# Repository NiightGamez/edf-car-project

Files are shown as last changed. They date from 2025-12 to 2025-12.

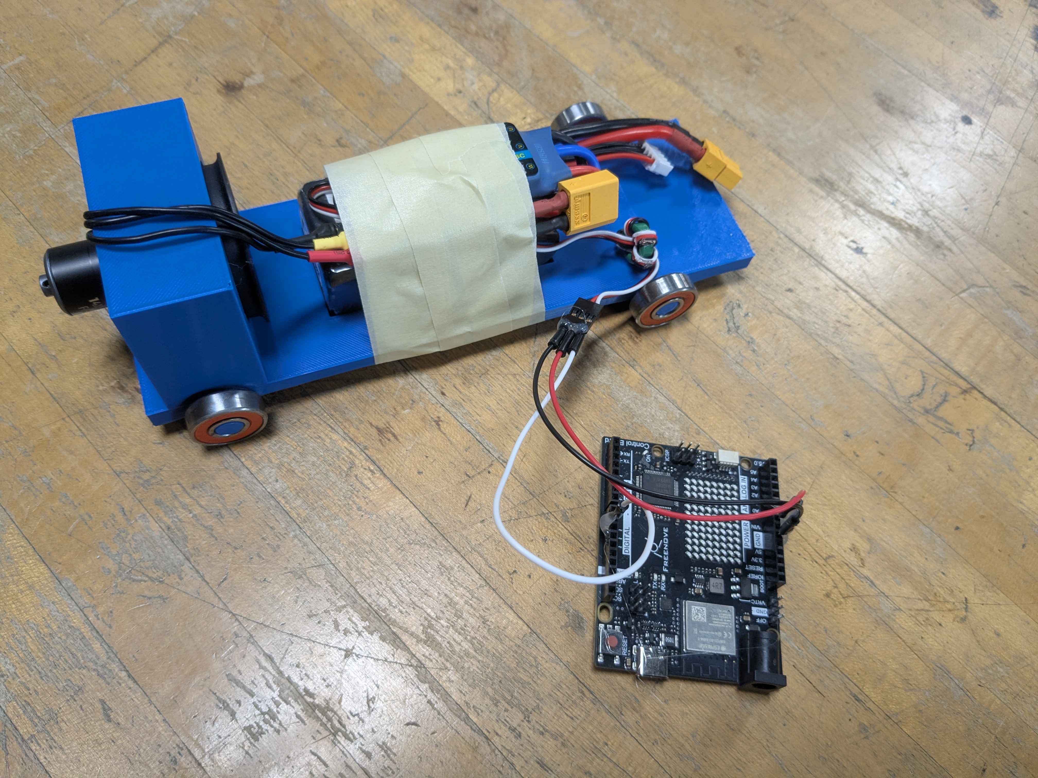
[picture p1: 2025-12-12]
PXL_20251212_173652594.jpg

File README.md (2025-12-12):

# 🚀 Pinewood Derby Ducted Fan Car Control System

This system uses an **Arduino Uno R4 WiFi** board as the master controller for a ducted fan Pinewood Derby car. It features BLE-required arming for safety, dual trigger modes (Ultrasonic Auto-Start or BLE Manual Trigger), and real-time status feedback via the onboard LED Matrix and Serial Monitor.

## 📋 Parts List

| Component | Function | Status |
| :--- | :--- | :--- |
| **Microcontroller**  | Arduino Uno R4 WiFi (or Freenove V5) | **Have** |
| **Trigger Sensor** | HC-SR04 Ultrasonic Sensor | **Have** |
| **Motor Controller** | 30A Brushless Electronic Speed Controller (ESC) | **Have** |
| **Propulsion** | 30mm Ducted Fan Unit (Brushless Motor) | **Have** |
| **Power** | 3S 11.1V 1500mAh LiPo Battery | **Have** |
## 💡 System Logic

1.  **Safety Master Key:** The system is completely inert (**DISARMED**) until a phone connects via BLE.
2.  **Arming:** Connecting via BLE sends the `THROTTLE_MIN` pulse to the ESC, arming the motor controller and enabling the trigger system.
3.  **Mode Select:** The BLE connection allows the user to switch between **MANUAL TRIGGER** and **SENSOR AUTO-TRIGGER** mode.
4.  **Race:** When triggered, the system simulates a full throttle run for 3 seconds.
## Arming:
- **BLE IS REQUIRED**
	- Connect with nRF Connnect
	```
	UUID Ending with 002
		- Set to 01 for Manual Trigger Mode (Disables sensor. Car is fired only by BLE Command)
		- Set to 02 Enables sensor. (Car fires automatically when pin drops)
	UUID Ending with 001
		- Set to 01 for Start Race/Fire Engine (Manual Sensor Overide) 	  
	```
	
## 🛠️ Initial Setup Instructions

1.  **Install Libraries:** In the Arduino IDE, install the following libraries:
    * `Servo` (Standard library)
    * `Arduino_LED_Matrix` (For the onboard matrix)
    * `ArduinoBLE` (For Bluetooth Low Energy control)

2.  **Upload Code:** Copy the contents of edf_car.ino` and upload it to your Arduino board.

3.  **BLE Connection (Master Key):**
    * Download **nRF Connect** on your Android phone.
    * Connect the battery to the ESC.
    * Scan for the device **`DerbyCarV5`** and connect. The system will switch from **DISARMED** (Matrix clear) to **MANUAL READY** (Matrix full border).

4.  **Mode Switching via BLE:**
    * Find the **Mode Characteristic** (UUID ending in `...0002`).
    * **Manual Trigger Mode:** Write Hex value **`01`**. (Default mode).
    * **Sensor Auto-Trigger Mode:** Write Hex value **`02`**.

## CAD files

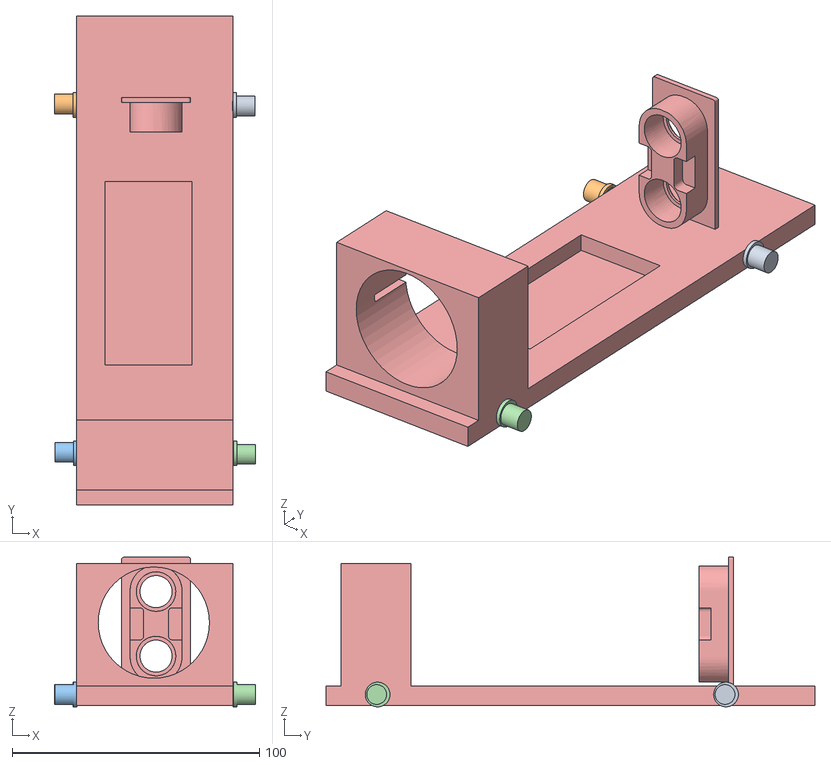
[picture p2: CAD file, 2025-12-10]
cad-files/tinker.obj
81.3 x 197.9 x 60.6
obj_0
obj_1
obj_2
obj_3
obj_4

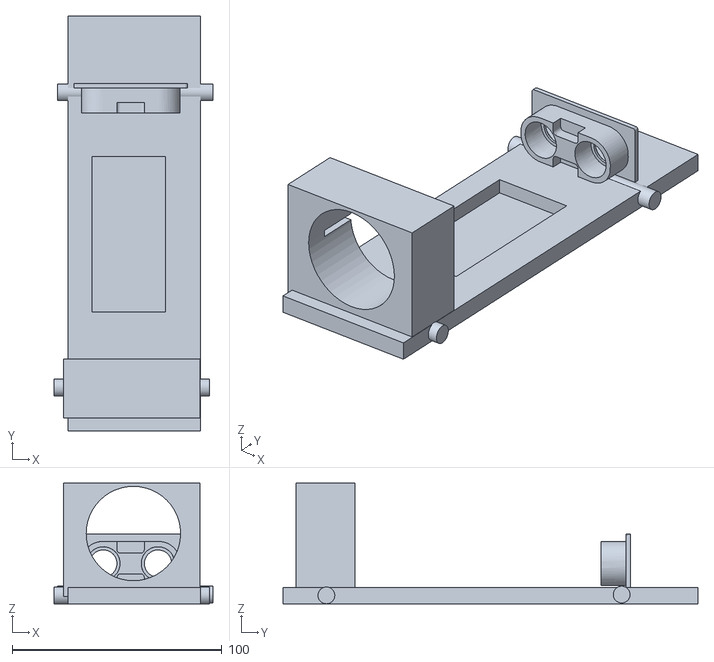
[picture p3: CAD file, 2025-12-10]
cad-files/Car3v3.stl
75.7 x 197.9 x 57.5

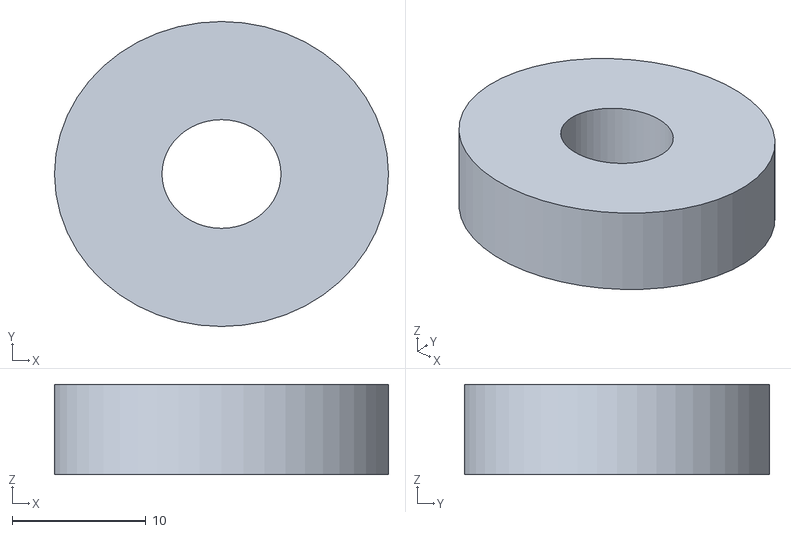
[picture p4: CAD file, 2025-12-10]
cad-files/wheeltest.stl
25.0 x 22.8 x 6.75

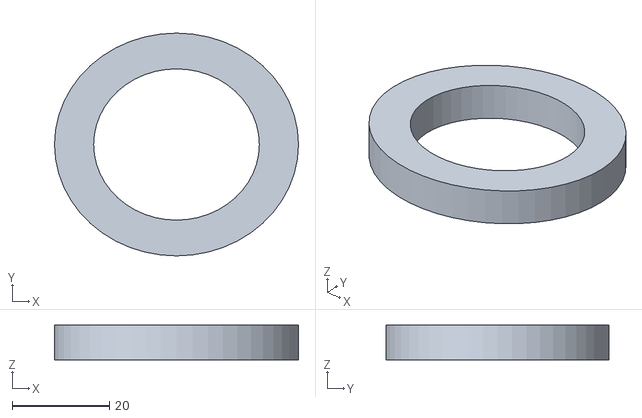
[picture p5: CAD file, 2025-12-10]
cad-files/wheeltest2.stl
50.1 x 45.8 x 7.15

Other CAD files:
cad-files/CarV4.stl

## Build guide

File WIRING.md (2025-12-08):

# ⚡ Wiring and Power Flow Diagram

**⚠️ WARNING:** The LiPo battery supplies 11.1V. Use caution. Ensure the **Fan Motor is disconnected** from the ESC during initial setup and testing. The ESC's BEC provides safe 5V power to the Arduino.

## 🔌 Signal and Control Connections

| Component | Pin (Wire Color) | Arduino Uno R4 Pin | Notes |
| :--- | :--- | :--- | :--- |
| **ESC Signal** | Signal (White) | **D9** | PWM output for throttle control. |
| **Ultrasonic Trigger**  | Trig (Red) | **D5** | Sends the sonic pulse. |
| **Ultrasonic Echo** | Echo (Orange) | **D6** | Receives the reflected pulse. |
| **Ultrasonic VCC (5V)** | VCC (Brown) | **Power 5v** | Sends 5V power to sensor |
| **Ultrasonic GND** | GND (Yellow) | **Power GND** | Supplies ground for sensor |

## 🔋 Power Connections

| Component | Pin (Wire Color) | Arduino Uno R4 Pin | Voltage |
| :--- | :--- | :--- | :--- |
| **LiPo Battery** (11.1V) | Large Red/Black | Connects ONLY to **30A ESC Power Input** | High Power |
| **ESC BEC Output** | Red | **5V Pin** | Powers the Arduino. |
| **ESC BEC Output** | Black/Brown | **GND Pin** | Common Ground. |

## Power Flow Summary

1.  **LiPo** $\rightarrow$ **ESC Power Input** (11.1V)
2.  **ESC** $\rightarrow$ **Ducted Fan Motor** (Controls motor speed)
3.  **ESC BEC** $\rightarrow$ **Arduino 5V/GND** (5V regulated power)
4.  **Arduino** $\rightarrow$ **HC-SR04** (Powered by 5V rail)

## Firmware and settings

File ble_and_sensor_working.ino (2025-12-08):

#include <Servo.h>

#include "Arduino_LED_Matrix.h"

#include <ArduinoBLE.h>

  

// Initialize Objects

Servo fanESC;

ArduinoLEDMatrix matrix;

  

// --- Pin Definitions ---

const int ESC_PIN = 9;

const int TRIG_PIN = 5;

const int ECHO_PIN = 6;

  

// --- Sensor & Control Constants ---

const float SPEED_OF_SOUND = 0.0343;

const int LAUNCH_THRESHOLD_CM = 3.1; // Fan ON if distance > 10 cm or Out of Range

const int SHUTDOWN_THRESHOLD_CM = 3; // Fan OFF if distance <= 9 cm

  

// --- CRITICAL THROTTLE CONSTANTS ---

const int THROTTLE_MIN = 1000; // 0% throttle (Arming and Stopping)

const int THROTTLE_MAX = 2000; // 100% throttle

  

// --- State Variables (Defined globally) ---

bool isArmed = false;

bool sensor_enabled = false;

bool isFanRunning = false;

int blink_state = 0;

  

// Track the current mode for change detection

enum Mode { MODE_DISARMED, MODE_MANUAL_READY, MODE_FAN_ON, MODE_SENSOR_READY };

Mode current_mode = MODE_DISARMED;

  

// --- BLE Definitions (Defined globally) ---

BLEService carService("19B10000-E8F2-537E-4F6C-D104768A1214");

BLEIntCharacteristic startCommandCharacteristic("19B10001-E8F2-537E-4F6C-D104768A1214", BLERead | BLEWrite);

BLEIntCharacteristic modeCharacteristic("19B10002-E8F2-537E-4F6C-D104768A1214", BLERead | BLEWrite);

  

// --- LED Matrix Patterns (Defined globally) ---

uint8_t BLE_CONNECTED_PATTERN[8][12] = {

{ 1, 1, 1, 1, 1, 1, 1, 1, 1, 1, 1, 1 }, { 1, 0, 0, 0, 0, 0, 0, 0, 0, 0, 0, 1 },

{ 1, 0, 0, 0, 0, 0, 0, 0, 0, 0, 0, 1 }, { 1, 0, 0, 0, 0, 0, 0, 0, 0, 0, 0, 1 },

{ 1, 0, 0, 0, 0, 0, 0, 0, 0, 0, 0, 1 }, { 1, 0, 0, 0, 0, 0, 0, 0, 0, 0, 0, 1 },

{ 1, 0, 0, 0, 0, 0, 0, 0, 0, 0, 0, 1 }, { 1, 1, 1, 1, 1, 1, 1, 1, 1, 1, 1, 1 }

};

uint8_t FAN_ON_PATTERN[8][12] = {

{ 1, 1, 1, 1, 1, 1, 1, 1, 1, 1, 1, 1 }, { 1, 1, 1, 1, 1, 1, 1, 1, 1, 1, 1, 1 },

{ 1, 1, 1, 1, 1, 1, 1, 1, 1, 1, 1, 1 }, { 1, 1, 1, 1, 1, 1, 1, 1, 1, 1, 1, 1 },

{ 1, 1, 1, 1, 1, 1, 1, 1, 1, 1, 1, 1 }, { 1, 1, 1, 1, 1, 1, 1, 1, 1, 1, 1, 1 },

{ 1, 1, 1, 1, 1, 1, 1, 1, 1, 1, 1, 1 }, { 1, 1, 1, 1, 1, 1, 1, 1, 1, 1, 1, 1 }

};

uint8_t SWITCH_PATTERN[8][12] = {

{ 1, 1, 1, 1, 1, 1, 1, 1, 1, 1, 1, 1 }, { 0, 0, 0, 0, 0, 0, 0, 0, 0, 0, 0, 0 },

{ 1, 1, 1, 1, 1, 1, 1, 1, 1, 1, 1, 1 }, { 0, 0, 0, 0, 0, 0, 0, 0, 0, 0, 0, 0 },

{ 1, 1, 1, 1, 1, 1, 1, 1, 1, 1, 1, 1 }, { 0, 0, 0, 0, 0, 0, 0, 0, 0, 0, 0, 0 },

{ 1, 1, 1, 1, 1, 1, 1, 1, 1, 1, 1, 1 }, { 0, 0, 0, 0, 0, 0, 0, 0, 0, 0, 0, 0 }

};

uint8_t DISARMED_DOT[8][12] = {

{ 0, 0, 0, 0, 0, 0, 0, 0, 0, 0, 0, 0 }, { 0, 0, 0, 0, 0, 0, 0, 0, 0, 0, 0, 0 },

{ 0, 0, 0, 0, 0, 0, 0, 0, 0, 0, 0, 0 }, { 0, 0, 0, 0, 0, 1, 1, 0, 0, 0, 0, 0 },

{ 0, 0, 0, 0, 0, 1, 1, 0, 0, 0, 0, 0 }, { 0, 0, 0, 0, 0, 0, 0, 0, 0, 0, 0, 0 },

{ 0, 0, 0, 0, 0, 0, 0, 0, 0, 0, 0, 0 }, { 0, 0, 0, 0, 0, 0, 0, 0, 0, 0, 0, 0 }

};

  
  

// ====================================

// CORE FUNCTIONS

// ====================================

  

float getDistance_cm() {

digitalWrite(TRIG_PIN, LOW); delayMicroseconds(2);

digitalWrite(TRIG_PIN, HIGH); delayMicroseconds(10);

digitalWrite(TRIG_PIN, LOW);

long duration = pulseIn(ECHO_PIN, HIGH, 30000);

if (duration == 0) return 400.0;

return (duration * SPEED_OF_SOUND) / 2.0;

}

  

void setFanPower(bool state) {

if (state == true) {

if (!isFanRunning) {

fanESC.writeMicroseconds(THROTTLE_MAX);

isFanRunning = true;

Serial.println("COMMAND: FAN ACTIVATED (2000us)");

}

} else {

if (isFanRunning) {

fanESC.writeMicroseconds(THROTTLE_MIN);

isFanRunning = false;

Serial.println("COMMAND: FAN SHUTDOWN (1000us)");

}

}

}

  

// ====================================

// DEBUG & DISPLAY FUNCTION

// ====================================

  

void displayStatus(float dist_cm, bool ble_connected) {

// 1. DETERMINE NEW MODE

Mode new_mode;

if (!isArmed) { new_mode = MODE_DISARMED; }

else if (isFanRunning) { new_mode = MODE_FAN_ON; }

else if (sensor_enabled) { new_mode = MODE_SENSOR_READY; }

else { new_mode = MODE_MANUAL_READY; }

  

// 2. DETECT SWITCH AND NOTIFY USER

if (new_mode != current_mode) {

current_mode = new_mode;

Serial.print("--------------------------------");

Serial.print("\nMODE SWITCHED TO: ");

if (new_mode == MODE_DISARMED) Serial.println("DISARMED");

else if (new_mode == MODE_FAN_ON) Serial.println("FAN IS RUNNING");

else if (new_mode == MODE_SENSOR_READY) Serial.println("SENSOR ACTIVE / FAN OFF");

else if (new_mode == MODE_MANUAL_READY) Serial.println("MANUAL READY / FAN OFF");

Serial.println("--------------------------------");

matrix.renderBitmap(SWITCH_PATTERN, 8, 12);

delay(50);

}

  

// 3. CONTINUOUS STATUS DISPLAY

blink_state = (blink_state + 1) % 10;

  

Serial.print("Status: ");

Serial.print(current_mode == MODE_DISARMED ? "DISARMED" : (isFanRunning ? "FAN ON" : "ARMED, FAN OFF"));

if (sensor_enabled) {

Serial.print(" | Dist: ");

if (dist_cm >= 400.0) { Serial.println("Out of Range"); }

else { Serial.print(dist_cm); Serial.println(" cm"); }

} else {

Serial.println(" | Sensor: Disabled");

}

  

// LED Matrix: Continuous Mode Indicator

if (current_mode == MODE_FAN_ON) { matrix.renderBitmap(FAN_ON_PATTERN, 8, 12); }

else if (current_mode == MODE_MANUAL_READY || current_mode == MODE_SENSOR_READY) {

matrix.renderBitmap(BLE_CONNECTED_PATTERN, 8, 12);

} else if (current_mode == MODE_DISARMED) {

if (blink_state > 5) { matrix.renderBitmap(DISARMED_DOT, 8, 12); }

else { matrix.clear(); }

}

}

  
  

// ====================================

// SETUP FUNCTION

// ====================================

void setup() {

Serial.begin(9600);

matrix.begin();

matrix.clear();

pinMode(TRIG_PIN, OUTPUT);

pinMode(ECHO_PIN, INPUT);

  

// --- BLE Setup (CRITICAL FIX: Initialize BLE first) ---

if (!BLE.begin()) {

Serial.println("!!! FATAL ERROR: BLE initialization failed! Program Halted. !!!");

while (1);

}

// --- ESC Attach (Attach after BLE succeeds) ---

fanESC.attach(ESC_PIN);

// Attach BLE characteristics to service

BLE.setAdvertisedService(carService);

carService.addCharacteristic(startCommandCharacteristic);

BLE.addService(carService);

carService.addCharacteristic(modeCharacteristic);

BLE.addService(carService);

BLE.setLocalName("DerbyCarV5");

Serial.println("System Initialized. Awaiting BLE Connection to Arm ESC.");

current_mode = MODE_DISARMED;

BLE.advertise();

}

  

// ====================================

// LOOP FUNCTION (DIRECT SENSOR CONTROL)

// ====================================

void loop() {

BLEDevice central = BLE.central();

bool ble_connected = central;

float distance = 0.0;

  

// --- A. BLE-REQUIRED ARMING/DISARMING ---

if (ble_connected && !isArmed) {

Serial.println("\n--- BLE CONNECTED: ARMING ESC NOW (ESC Must Beep) ---");

fanESC.writeMicroseconds(THROTTLE_MIN);

isArmed = true;

delay(100);

}

if (!ble_connected && isArmed) {

Serial.println("\n--- BLE DISCONNECTED: DISARMING CAR ---");

setFanPower(false); // Shut down fan

isArmed = false;

current_mode = MODE_DISARMED;

}

// --- B. BLE COMMAND HANDLING ---

if (isArmed) {

// 1. CHECK FOR MODE CHANGE COMMAND (Fixes Mode Switch Issue)

if (modeCharacteristic.written()) {

int mode_cmd = modeCharacteristic.value();

if (mode_cmd == 2) {

sensor_enabled = true;

Serial.println("Mode set to SENSOR AUTO-TRIGGER.");

} else {

sensor_enabled = false;

Serial.println("Mode set to MANUAL TRIGGER.");

}

modeCharacteristic.writeValue(mode_cmd); // Acknowledge write

}

// 2. CHECK FOR FAN ON/OFF COMMAND (Manual override for testing)

if (startCommandCharacteristic.written()) {

int command = startCommandCharacteristic.value();

if (command == 1) { setFanPower(true); } else if (command == 0) { setFanPower(false); }

startCommandCharacteristic.writeValue(command);

}

}

  

// --- C. DIRECT SENSOR CONTROL LOGIC (MODIFIED FOR OUT OF RANGE) ---

if (isArmed && sensor_enabled) {

distance = getDistance_cm();

// 1. SAFETY SHUTDOWN CHECK: Turn fan OFF if distance is <= 9 cm

if (distance <= SHUTDOWN_THRESHOLD_CM) {

if (isFanRunning) {

Serial.println("SENSOR SHUTDOWN: Obstacle <= 9cm. FAN OFF.");

}

setFanPower(false);

}

// 2. LAUNCH/KEEP RUNNING CHECK: Turn fan ON if distance > 10 cm OR out of range (400cm)

else if (distance > LAUNCH_THRESHOLD_CM || distance == 400.0) {

if (!isFanRunning) {

Serial.println("SENSOR TRIGGER/RUNNING: Distance > 10cm or Out of Range. FAN ON.");

}

setFanPower(true);

}

// 3. IDLE ZONE (Between 9.01 cm and 10 cm): Fan remains OFF by default.

}

// D. Display current status

displayStatus(distance, ble_connected);

delay(50);

}

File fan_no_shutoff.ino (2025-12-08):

#include <Servo.h>

  

// Initialize ESC Object

Servo fanESC;

  

// --- Pin Definitions ---

const int ESC_PIN = 9;

const int TRIG_PIN = 5;

const int ECHO_PIN = 6;

  

// --- ESC & Race Constants ---

const int THROTTLE_MIN = 1000; // 0% throttle (Arming and Stopping)

const int THROTTLE_MAX = 2000; // 100% throttle

const float SPEED_OF_SOUND = 0.0343; // cm/microsecond

const int STAGING_THRESHOLD_CM = 10; // Distance to be considered 'staged' (e.g., pin is there)

const int RACE_DURATION_MS = 3000;

  

// --- State Variables ---

bool isArmed = false; // True after ESC arming sequence completes

bool isRacing = false; // True during the 3-second motor run

bool isStaged = false; // True if the starting pin is currently in front of the sensor

  

// ====================================

// CORE FUNCTION: MEASURE DISTANCE

// ====================================

float getDistance_cm() {

// Clear the trigger pin

digitalWrite(TRIG_PIN, LOW);

delayMicroseconds(2);

// Send a 10µs pulse to trigger

digitalWrite(TRIG_PIN, HIGH);

delayMicroseconds(10);

digitalWrite(TRIG_PIN, LOW);

// Measure the duration of the incoming pulse

long duration = pulseIn(ECHO_PIN, HIGH, 30000);

if (duration == 0) return 400.0; // Return high value if no echo within 30ms

// Calculate distance: (Duration * Speed of Sound) / 2

return (duration * SPEED_OF_SOUND) / 2.0;

}

  

// ====================================

// CORE FUNCTION: ACTIVATE FAN

// ====================================

void fireEngine() {

if (!isRacing && isArmed) {

Serial.println("!!! RACE START: FULL THRUST ACTIVATED !!!");

isRacing = true;

isStaged = false; // Reset staging flag

  

// --- ACTIVATE MOTOR ---

fanESC.writeMicroseconds(THROTTLE_MAX); // Run fan at 100%

Serial.print("Running for ");

Serial.print(RACE_DURATION_MS / 1000);

Serial.println(" seconds...");

delay(RACE_DURATION_MS); // Hold throttle for race duration

// --- STOP MOTOR ---

fanESC.writeMicroseconds(THROTTLE_MIN); // Stop the motor

isRacing = false;

isArmed = false; // Disarm until reset or power cycle

Serial.println("RACE ENDED. System is DISARMED.");

}

}

  

// ====================================

// SETUP FUNCTION

// ====================================

void setup() {

Serial.begin(9600);

fanESC.attach(ESC_PIN);

pinMode(TRIG_PIN, OUTPUT);

pinMode(ECHO_PIN, INPUT);

// --- ESC ARMING SEQUENCE (Copied from your working code) ---

Serial.println("--- ESC ARMING START ---");

Serial.println("STEP 1: Plug in LiPo battery NOW.");

Serial.println("Waiting 5 seconds for ESC to arm at min throttle...");

fanESC.writeMicroseconds(THROTTLE_MIN); // Send the minimum pulse

delay(5000);

isArmed = true;

Serial.println("STEP 2: ARMING COMPLETE. System is ready to stage.");

Serial.println("--------------------------------");

}

  

// ====================================

// LOOP FUNCTION (SENSOR LOGIC)

// ====================================

void loop() {

// Only check sensor if the system is armed and not already racing

if (isArmed && !isRacing) {

float distance = getDistance_cm();

// 1. Update staging memory

if (distance <= STAGING_THRESHOLD_CM) {

if (!isStaged) {

Serial.println("STATUS: STAGED. Waiting for Pin Drop.");

}

isStaged = true; // Pin is in place

}

// 2. RACE TRIGGER CHECK: Launch if car was staged AND distance increases

if (isStaged && distance > STAGING_THRESHOLD_CM) {

Serial.println("TRIGGER: Pin dropped (Distance > 10cm).");

fireEngine();

}

}

// If system is disarmed after a race, keep motor off

if (!isArmed) {

fanESC.writeMicroseconds(THROTTLE_MIN);

}

delay(50); // Small delay for loop stability

}
